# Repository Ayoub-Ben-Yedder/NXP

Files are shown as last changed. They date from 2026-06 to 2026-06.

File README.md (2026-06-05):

# NXP Line Following Robot

An autonomous 2line-following robot built on the Teensy microcontroller with advanced vision-based steering using Pixy2 camera. Designed for precision line tracking with intersection detection and obstacle avoidance.

## Project Overview

This project implements a sophisticated autonomous robot controller that:
- Follows lines detected by Pixy2 camera vision system
- Intelligently handles intersections and corners
- Detects and responds to obstacles using ultrasonic distance sensor
- Recognizes finish line patterns and stops safely
- Applies advanced steering algorithms for smooth, stable tracking

## Hardware Components

### Microcontroller
- **Teensy** (primary controller)

### Sensors
- **Pixy2 Camera** - Line detection and vector tracking
- **HC-SR04 Ultrasonic Sensor** - Distance measurement for obstacle detection
  - TRIG: Pin 14
  - ECHO: Pin 15

### Actuators
- **Servo Motor** - Steering control (Pin 23)
- **DC Motors (x2)** - Left and right propulsion
  - Left Motor: PWM (Pin 8), Direction (Pins 6-7)
  - Right Motor: PWM (Pin 18), Direction (Pins 20-19)

### Additional
- **LED Indicator** - Pin 22
- **Logic Level Converters** - For Pixy2 communication

## Electronics & PCB Design

The electronics are primarily a **Teensy 4.0 shield** custom designed with **KiCAD**. The shield integrates all necessary components (motor drivers, sensor interfaces, power distribution) onto a single PCB that stacks directly onto the Teensy 4.0 microcontroller, providing a clean and compact solution for the robot.

### Schematics
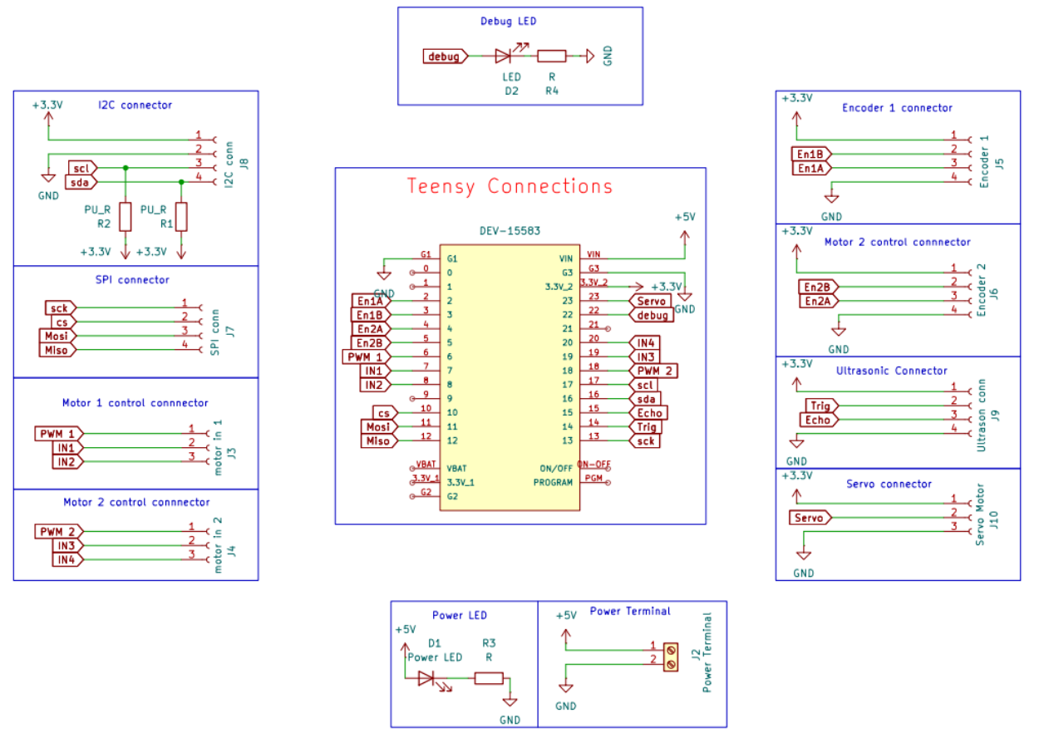
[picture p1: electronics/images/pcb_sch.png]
PCB Schematic


### PCB Layout
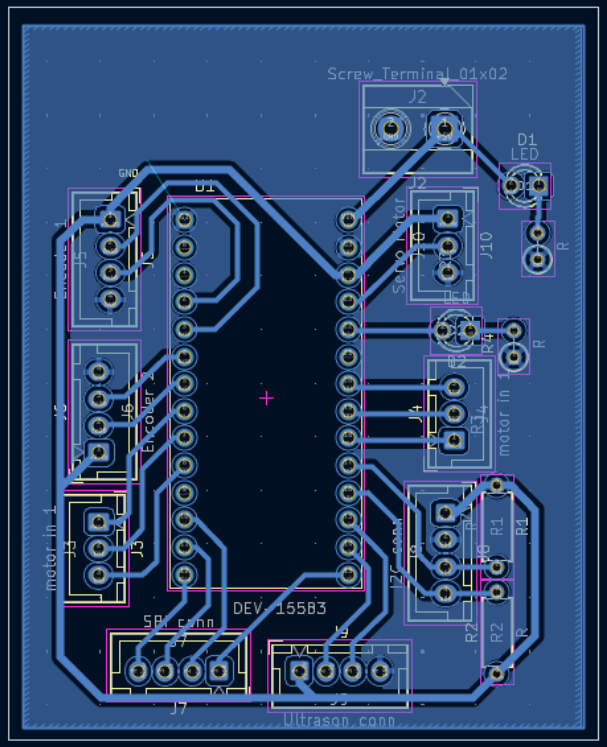
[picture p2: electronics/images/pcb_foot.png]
PCB Footprint


### 3D View
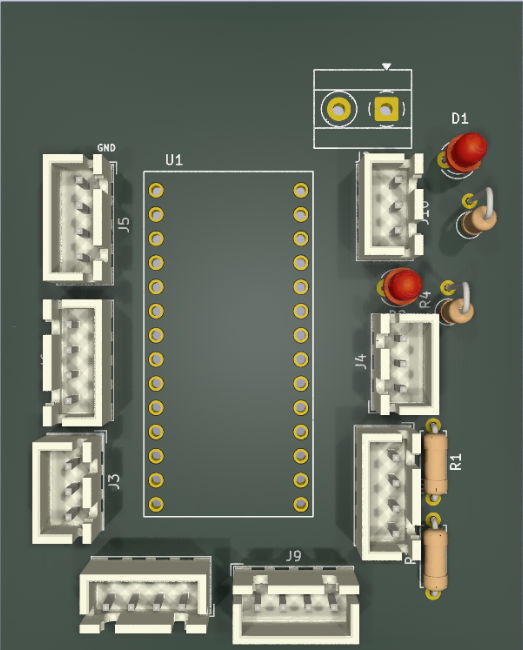
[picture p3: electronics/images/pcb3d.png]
PCB 3D View


All design files are located in the `electronics/` directory.

## Mechanical Design

The mechanical design for this robot was adapted from the [NXP CUP FINALS](https://github.com/aminebensaid66/NXP-CUP-FINALS) repository. This includes the chassis, motor mounts, sensor brackets, and other structural components required for the robot assembly.

## Pin Configuration

```
PWM1 = 8      (Left motor speed)
IN1 = 6       (Left motor direction)
IN2 = 7       (Left motor direction)
PWM2 = 18     (Right motor speed)
IN3 = 20      (Right motor direction)
IN4 = 19      (Right motor direction)

LED = 22
ECHO = 15     (Ultrasonic echo)
TRIG = 14     (Ultrasonic trigger)
SERVO_PIN = 23 (Steering servo)
```

## Key Features

### 1. Advanced Line Following
- Processes up to 20 line vectors from Pixy2 camera
- Weighted steering algorithm that considers vector angles and lengths
- Minimum vector length filtering to ignore noise
- Soft steering limits to prevent oscillation

### 2. Intersection Detection
- Identifies corner types: top-left, top-right, bottom-left, bottom-right
- Analyzes angle between consecutive vectors (target ~90°)
- Applies directional corrections based on intersection position
- More aggressive steering during turns for accuracy

### 3. Steering Control
- **Center Angle:** 135° (neutral position)
- **Steering Range:** 90° (MAX_LEFT) to 180° (MAX_RIGHT)
- **Deadband:** ±15° around forward angle to filter horizontal noise
- **Soft Limiting:** Reduces extreme steering angles to prevent oscillation
- **Center Bias:** Gently pulls steering toward center for stability
- **Delay System:** Smooths steering inputs over 2 cycles

### 4. Obstacle Detection & Avoidance
- Continuously monitors distance via ultrasonic sensor
- Filtered readings (average of 3 samples) for stability
- **Stop Distance:** 15 cm - triggers reverse and stop
- Timeout handling for cases where no object is detected

### 5. Finish Line Recognition
- Detects horizontal line patterns (angle ≤ 15° from horizontal)
- Requires 2+ horizontal vectors within 5 pixels of each other
- Activation delay (10 seconds) to avoid false positives at start
- Triggers acceleration boost and obstacle check

## Build & Upload

This project uses **PlatformIO** for build and upload management.

### Prerequisites
- VSCode with PlatformIO extension
- Arduino IDE libraries (Pixy2, Servo)

### Building
```bash
pio run
```

### Uploading to Device
```bash
pio run --target upload
```

### Monitoring Serial Output
```bash
pio device monitor
```

## Algorithm Flow

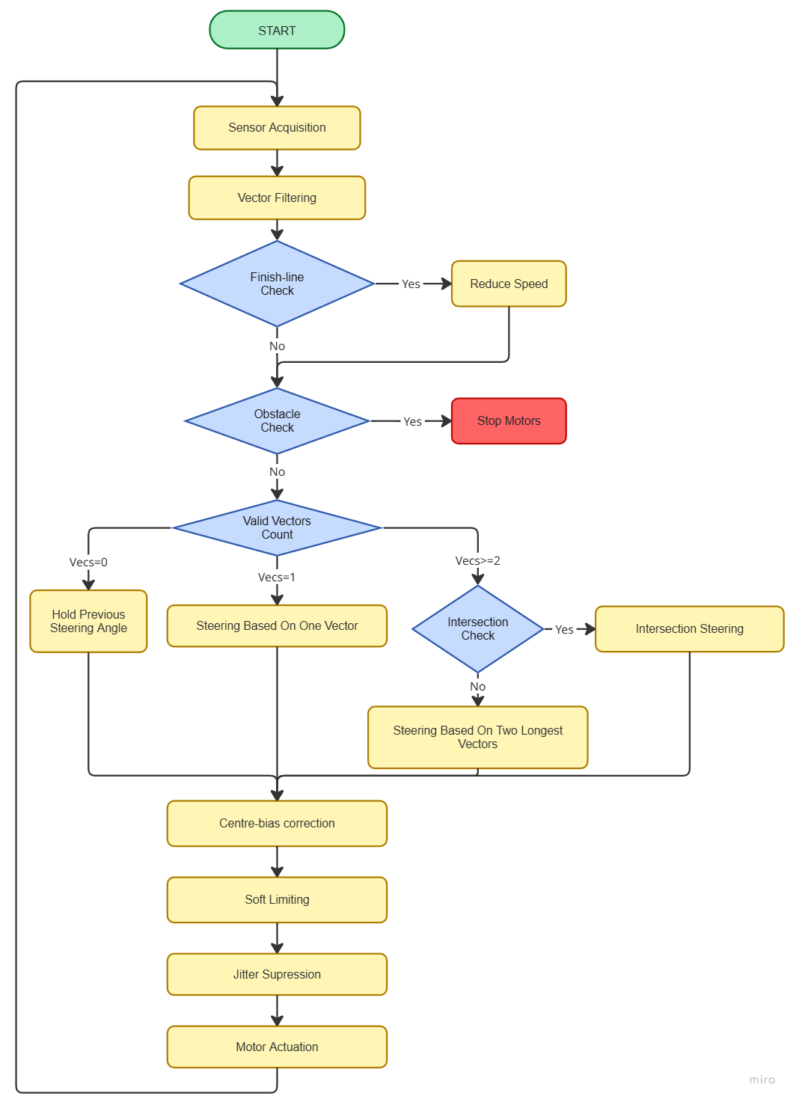
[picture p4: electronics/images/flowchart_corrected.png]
Algorithm Flowchart


1. **Initialization**
   - Configure PWM frequencies (20 kHz)
   - Initialize pins and servo to center
   - Initialize Pixy2 in line-tracking mode
   - Record start time for finish line delay

2. **Main Loop (runNXP)**
   - Read Pixy2 vectors
   - Filter vectors by length, angle, and position
   - Identify horizontal vectors for finish line detection
   - Sort vectors by length (longest first)
   - Compute steering angle based on vector count:
     - **0 vectors:** Maintain last angle
     - **1 vector:** Standard line following
     - **2+ vectors:** Check for intersection; if ~90° angle detected, apply intersection steering
   - Apply steering corrections (center bias, soft limits)
   - Implement steering delay system for smooth transitions
   - Check finish line and obstacle avoidance conditions

3. **Distance Monitoring**
   - Triggered after finish line detection
   - Backs up and stops if obstacle within STOP_DISTANCE

## Constants & Tuning Parameters

```cpp
MAX_VECTORS = 20          // Max vectors to process per frame
MIN_VECTOR_LENGTH = 10    // Minimum pixels for valid vector

CENTRE_ANGLE = 135        // Neutral steering position
MAX_RIGHT = 180           // Maximum right turn
MAX_LEFT = 90             // Maximum left turn

STOP_DISTANCE = 15        // cm - obstacle stop threshold

PIXY_FORWARD_ANGLE = 270  // Expected angle for straight tracking
PIXY_STEER_DEADBAND = 15  // Angle tolerance for horizontal detection
STEERING_DELAY_CYCLES = 2 // Smoothing delay for steering changes
STEERING_QUEUE_THRESHOLD = 2.0   // Threshold to queue steering change
STEERING_CENTER_BIAS = 5.0       // Pull toward center amount
STEERING_SOFT_LIMIT_START = 11   // When to start softening
STEERING_SOFT_LIMIT_FACTOR = 0.5 // Softening strength
CROSS_CORRECTION_ANGLE = 15      // Intersection correction
```

## Performance Notes

- **Steering Response:** Balanced between responsiveness and stability
- **Motor Speed:** Default 150 units for forward motion, 130 for finish line
- **Reverse Speed:** 100 units for obstacle avoidance
- **Frame Rate:** Dependent on Pixy2 refresh rate (typical ~50 FPS)

## Troubleshooting

| Issue | Solution |
|---|---|
| Robot doesn't follow line | Check Pixy2 is in "line" mode; verify camera focus; check lighting |
| Erratic steering | Increase STEERING_DELAY_CYCLES; adjust STEERING_CENTER_BIAS |
| Misses turns | Lower angle threshold in intersection detection; increase CROSS_CORRECTION_ANGLE |
| Oscillates | Enable soft limiting; increase STEERING_SOFT_LIMIT_FACTOR |
| Overshoots finish line | Reduce finish line acceleration value; increase STOP_DISTANCE |

## Project Structure

```
NXP/
├── src/
│   ├── main.cpp          # Main robot controller
│   └── README.md         # This file
├── include/
├── lib/
├── platformio.ini        # Build configuration
└── test/
```

## Future Enhancements

- PID control for smoother steering response
- Dynamic speed adjustment based on turn sharpness
- Gyro integration for improved angle estimation
- Adaptive threshold tuning based on lighting conditions
- Multi-point finish line detection for reliability

---

**Last Updated:** June 2026  
**Board:** Teensy  
**Camera:** Pixy2  
**Competition:** NXP

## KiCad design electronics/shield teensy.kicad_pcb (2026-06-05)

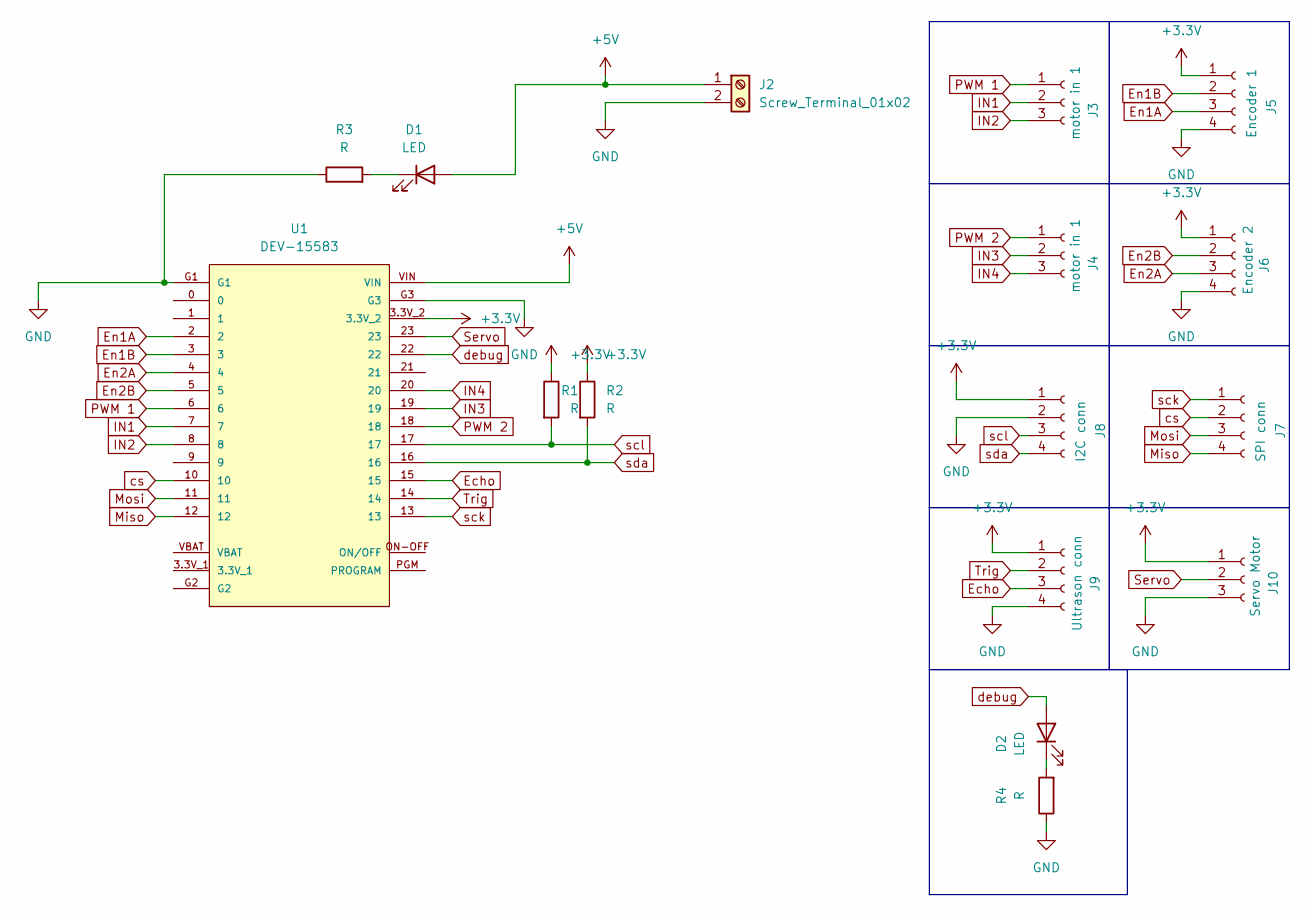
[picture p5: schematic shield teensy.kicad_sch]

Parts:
D1, D2: LED; LED_D3.0mm
J2: Screw_Terminal_01x02; TerminalBlock_MetzConnect_Type055_RT01502HDWU_1x02_P5.00mm_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
J3, J4: motor in 1; JST_XH_B3B-XH-A_1x03_P2.50mm_Vertical
J5: Encoder 1; JST_XH_B4B-XH-A_1x04_P2.50mm_Vertical
J6: Encoder 2; JST_XH_B4B-XH-A_1x04_P2.50mm_Vertical
J7: SPI conn; JST_XH_B4B-XH-A_1x04_P2.50mm_Vertical
J8: I2C conn; JST_XH_B4B-XH-A_1x04_P2.50mm_Vertical
J9: Ultrason conn; JST_XH_B4B-XH-A_1x04_P2.50mm_Vertical
J10: Servo Motor; JST_XH_B3B-XH-A_1x03_P2.50mm_Vertical
R1, R2: R; R_Axial_DIN0207_L6.3mm_D2.5mm_P7.62mm_Horizontal
R3, R4: R; R_Axial_DIN0207_L6.3mm_D2.5mm_P2.54mm_Vertical
U1: DEV-15583; MODULE_DEV-15583

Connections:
+3.3V: J5.1, J6.1, J8.1, J9.1, J10.1, R1.1, R2.1, U1.3.3V_2
+5V: D1.2 (A), J2.1, U1.VIN
Echo: J9.3, U1.15
En1A: J5.3, U1.2
En1B: J5.2, U1.3
En2A: J6.3, U1.4
En2B: J6.2, U1.5
GND: J2.2, J5.4, J6.4, J8.2, J9.4, J10.3, R3.1, R4.1, U1.G1, U1.G3
IN1: J3.2, U1.7
IN2: J3.3, U1.8
IN3: J4.2, U1.19
IN4: J4.3, U1.20
Miso: J7.4, U1.12
Mosi: J7.3, U1.11
unnamed: D1.1 (K), R3.2
unnamed: D2.1 (K), R4.2
PWM 1: J3.1, U1.6
PWM 2: J4.1, U1.18
Servo: J10.2, U1.23
Trig: J9.2, U1.14
cs: J7.2, U1.10
debug: D2.2 (A), U1.22
sck: J7.1, U1.13
scl: J8.3, R1.2, U1.17
sda: J8.4, R2.2, U1.16

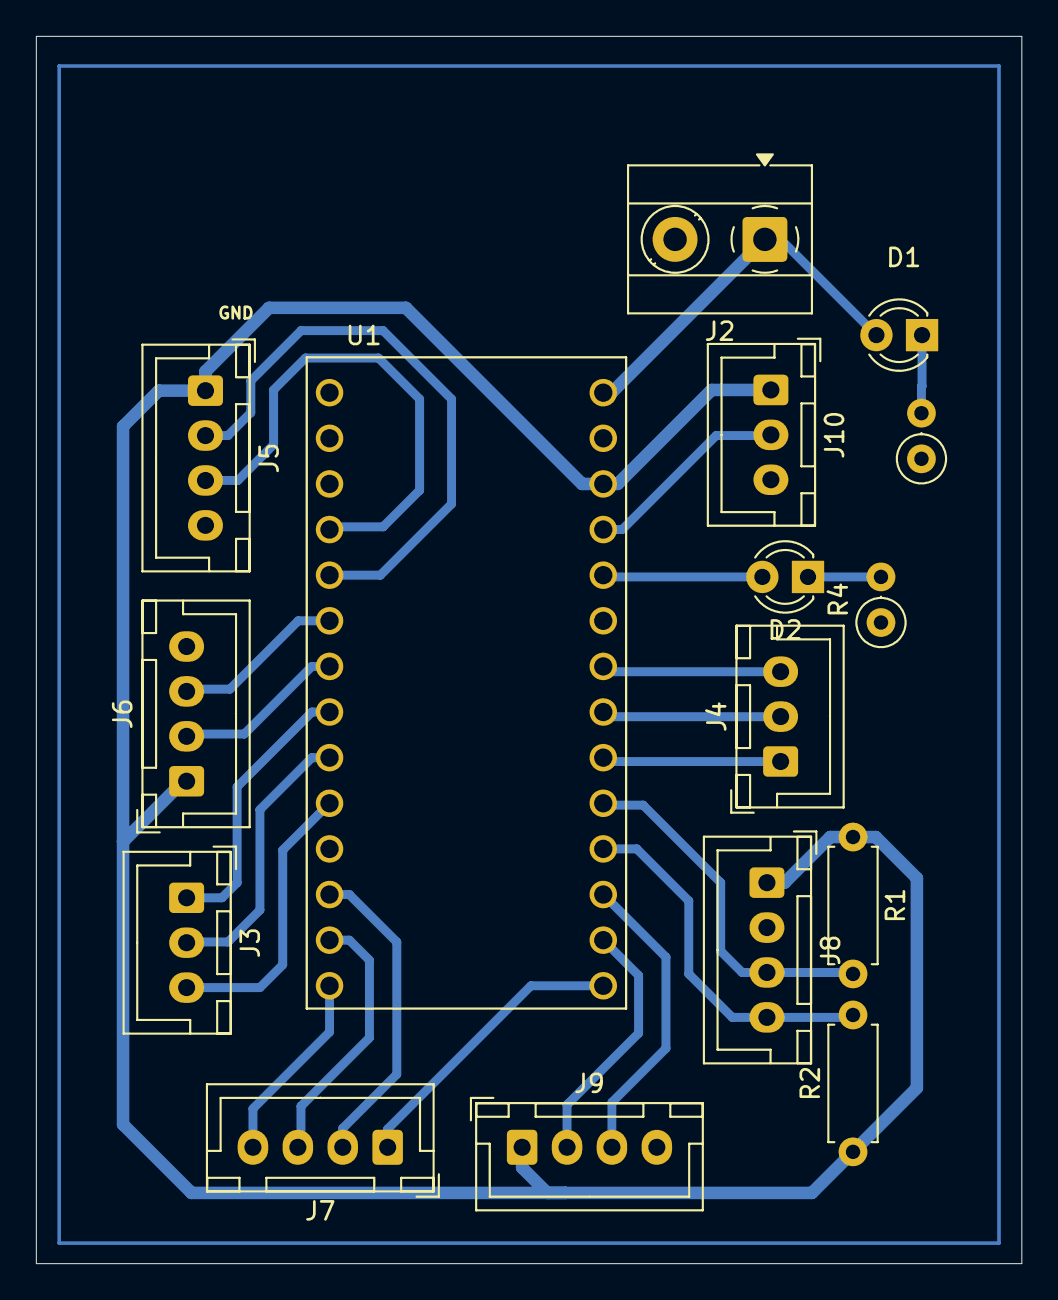
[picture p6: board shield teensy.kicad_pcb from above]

Board: 2 copper layers, 54.9 x 68.3 mm, 16 parts (0 on the bottom side), 25 nets.

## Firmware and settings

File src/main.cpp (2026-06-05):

#include <Arduino.h>
#include <Pixy2.h>
#include <Servo.h>
#include <Wire.h>

// pins definition
#define PWM1 8
#define IN1 6
#define IN2 7
#define PWM2 18
#define IN3 20
#define IN4 19

#define LED 22
#define ECHO 15
#define TRIG 14
#define SERVO_PIN 23

// constants definition

#define MAX_VECTORS 20
#define MIN_VECTOR_LENGTH 10

#define CENTRE_ANGLE 135
#define MAX_RIGHT CENTRE_ANGLE + 45
#define MAX_LEFT CENTRE_ANGLE - 45

#define STOP_DISTANCE 15

#define TOP_LEFT_CORNER 1
#define TOP_RIGHT_CORNER 2
#define BOTTOM_LEFT_CORNER 3
#define BOTTOM_RIGHT_CORNER 4

#define CROSS_CORRECTION_ANGLE 15.0f

constexpr float PIXY_FORWARD_ANGLE = 270.0;
constexpr float PIXY_STEER_DEADBAND = 15.0;
constexpr uint8_t STEERING_DELAY_CYCLES = 2;
constexpr float STEERING_QUEUE_THRESHOLD = 2.0;
constexpr float STEERING_CENTER_BIAS = 5.0;
constexpr float STEERING_SOFT_LIMIT_START = 11.0;
constexpr float STEERING_SOFT_LIMIT_FACTOR = 0.5;

Servo steer_servo;
Pixy2 pixy;
static float lastSteeringAngle = CENTRE_ANGLE;
static float pendingSteeringAngle = CENTRE_ANGLE;
static uint8_t steeringDelayCounter = 0;

bool finishLineDetected = false;

unsigned long startTime;

long readDistance()
{
  digitalWrite(TRIG, LOW);
  delayMicroseconds(2);

  digitalWrite(TRIG, HIGH);
  delayMicroseconds(10);
  digitalWrite(TRIG, LOW);

  long duration = pulseIn(ECHO, HIGH, 5000); // timeout 5ms
  if (duration == 0)
  {
    return 99; // timeout, no object detected
  }
  long distance = duration * 0.034 / 2;       // cm

  return distance;
}

long readDistanceFiltered()
{
  const int numReadings = 3;
  long readings[numReadings];
  long sum = 0;

  for (int i = 0; i < numReadings; i++)
  {
    readings[i] = readDistance();
    sum += readings[i];
    delay(1);
  }

  return sum / numReadings;
}

void initPixy()
{
  pixy.init();
  pixy.changeProg("line");
}

void steer(int angle)
{
  angle = constrain(angle, MAX_LEFT, MAX_RIGHT);
  steer_servo.write(angle);
}

void run(int speedLeft, int speedRight)
{
  speedLeft = constrain(speedLeft, -255, 255);
  speedRight = constrain(speedRight, -255, 255);

  if (speedRight >= 0)
  {
    analogWrite(PWM2, speedRight);
    digitalWrite(IN3, HIGH);
    digitalWrite(IN4, LOW);
  }
  else
  {
    analogWrite(PWM2, -speedRight);
    digitalWrite(IN3, LOW);
    digitalWrite(IN4, HIGH);
  }

  if (speedLeft >= 0)
  {
    analogWrite(PWM1, speedLeft);
    digitalWrite(IN1, LOW);
    digitalWrite(IN2, HIGH);
  }
  else
  {
    analogWrite(PWM1, -speedLeft);
    digitalWrite(IN1, HIGH);
    digitalWrite(IN2, LOW);
  }
}
// compute the angle of a vector in degrees, where 0 is to the right and increases counterclockwise
float computeAngle(const Vector &vec)
{
  float res = atan2(vec.m_y1 - vec.m_y0, vec.m_x1 - vec.m_x0) * 180.0 / PI;
  while (res < 0)
  {
    res += 360;
  }
  while (res >= 360)
  {
    res -= 360;
  }
  return res;
}
// compute the length of a vector
float computeLength(const Vector &vec)
{
  return sqrt(pow(vec.m_x1 - vec.m_x0, 2) + pow(vec.m_y1 - vec.m_y0, 2));
}
// normalize an angle to be within (0, 360)
float normalizeAngle(float angle)
{
  while (angle < 0.0)
  {
    angle += 360.0;
  }
  while (angle >= 360.0)
  {
    angle -= 360.0;
  }
  return angle;
}

bool isHorizontalAngle(float angle)
{
  angle = normalizeAngle(angle);
  return (angle <= PIXY_STEER_DEADBAND || angle >= 360.0 - PIXY_STEER_DEADBAND) || (fabs(angle - 180.0) <= PIXY_STEER_DEADBAND);
}

float mapFloat(float x, float inMin, float inMax, float outMin, float outMax)
{
  return (x - inMin) * (outMax - outMin) / (inMax - inMin) + outMin;
}
// compute the smallest difference between two angles, result is in range (-180, 180)
float angleDelta(float from, float to)
{
  float delta = normalizeAngle(to) - normalizeAngle(from);
  while (delta <= -180.0)
  {
    delta += 360.0;
  }
  while (delta > 180.0)
  {
    delta -= 360.0;
  }
  return delta;
}

float computeSteeringAngle(const Vector *vectors, uint8_t numVectors)
{
  float weightedDelta = 0.0;
  float totalWeight = 0.0;

  for (uint8_t i = 0; i < numVectors; i++)
  {
    float angle = computeAngle(vectors[i]);
    float length = computeLength(vectors[i]);
    float delta = angleDelta(PIXY_FORWARD_ANGLE, angle);

    if (fabs(delta) > 90.0)
    {
      delta = angleDelta(PIXY_FORWARD_ANGLE, normalizeAngle(angle + 180.0));
    }

    float weight = max(length, 1.0f);
    weightedDelta += delta * weight;
    totalWeight += weight;
  }

  float avgDelta = totalWeight > 0.0 ? weightedDelta / totalWeight : 0.0;
  avgDelta = constrain(avgDelta, -45.0, 45.0);
  return mapFloat(avgDelta, -45.0, 45.0, MAX_LEFT, MAX_RIGHT);
}
// bias the steering angle slightly toward the center to help with recovery when we drift to the sides
float biasSteeringTowardCenter(float steeringAngle)
{
  if (steeringAngle > CENTRE_ANGLE)
  {
    return max(CENTRE_ANGLE, steeringAngle - STEERING_CENTER_BIAS);
  }
  if (steeringAngle < CENTRE_ANGLE)
  {
    return min(CENTRE_ANGLE, steeringAngle + STEERING_CENTER_BIAS);
  }
  return steeringAngle;
}
// when the steering angle is beyond a certain threshold from the center, we start to soften it to avoid oversteering and oscillations
float softenExtremeSteering(float steeringAngle)
{
  float delta = steeringAngle - CENTRE_ANGLE;
  float absDelta = fabs(delta);
  if (absDelta <= STEERING_SOFT_LIMIT_START)
  {
    return steeringAngle;
  }

  float sign = delta > 0 ? 1.0f : -1.0f;
  float extra = absDelta - STEERING_SOFT_LIMIT_START;
  float softenedExtra = extra * STEERING_SOFT_LIMIT_FACTOR;
  return CENTRE_ANGLE + sign * (STEERING_SOFT_LIMIT_START + softenedExtra);
}

void sortVectorsByLength(Vector *vectors, uint8_t numVectors)
{
  for (uint8_t i = 0; i < numVectors - 1; i++)
  {
    for (uint8_t j = 0; j < numVectors - i - 1; j++)
    {
      float length1 = computeLength(vectors[j]);
      float length2 = computeLength(vectors[j + 1]);
      if (length1 < length2)
      {
        Vector temp = vectors[j];
        vectors[j] = vectors[j + 1];
        vectors[j + 1] = temp;
      }
    }
  }
}

float applyCorrection(const Vector *vectors, uint8_t numVectors, float targetSteering)
{
 if (numVectors == 1)
  {
    float mainVectorCenterX = (vectors[0].m_x0 + vectors[0].m_x1) / 2.0f; // (x0+x1)/2 mte3 atwel vecteur
    if (fabs(targetSteering - CENTRE_ANGLE) <= 10.0f && mainVectorCenterX >= 20.0f && mainVectorCenterX <= 60.0f)
    {
      float correction = 0.0f;
      if (mainVectorCenterX >= 20.0f && mainVectorCenterX < 40.0f)
      {
        correction = 15.0f; // Small turn to the right
      }
      else if (mainVectorCenterX >= 40.0f && mainVectorCenterX <= 60.0f)
      { 
        correction = -15.0f; // Small turn to the left
      }

      targetSteering = constrain(targetSteering + correction, MAX_LEFT, MAX_RIGHT);
    }
  }
  return targetSteering;
}

float dotProduct(const Vector &v1, const Vector &v2)
{
  return (v1.m_x1 - v1.m_x0) * (v2.m_x1 - v2.m_x0) + (v1.m_y1 - v1.m_y0) * (v2.m_y1 - v2.m_y0);
}

float computeAngleBetweenVectors(const Vector &v1, const Vector &v2)
{
  float mag1 = computeLength(v1);
  float mag2 = computeLength(v2);
  if (mag1 == 0 || mag2 == 0) return 0;
  float dot = dotProduct(v1, v2);
  float cosTheta = dot / (mag1 * mag2);
  cosTheta = constrain(cosTheta, -1.0f, 1.0f);
  return acos(cosTheta) * 180.0 / PI;
}

void stopBox(){
  
  long distance = readDistanceFiltered();
  if(distance < STOP_DISTANCE){
    run(-100,-100);
    delay(200);
    run(0,0);
    while(true);
  }
}
// Identify the type of intersection (corner) formed by two vectors, return 0 if no clear corner is identified, or one of the corner constants if identified
int identifyCase(Vector v1, Vector v2) {
    struct Point { float x, y; };

    Point p1a = {(float)v1.m_x0, (float)v1.m_y0};
    Point p1b = {(float)v1.m_x1, (float)v1.m_y1};
    Point p2a = {(float)v2.m_x0, (float)v2.m_y0};
    Point p2b = {(float)v2.m_x1, (float)v2.m_y1};

    auto distSq = [](Point a, Point b) { 
        return std::pow(a.x - b.x, 2) + std::pow(a.y - b.y, 2); 
    };

    // Find which two ends are the corner
    float d00 = distSq(p1a, p2a);
    float d01 = distSq(p1a, p2b);
    float d10 = distSq(p1b, p2a);
    float d11 = distSq(p1b, p2b);

    Point corner, far1, far2;
    float minDist = std::min({d00, d01, d10, d11});

    if (minDist == d00) { corner = p1a; far1 = p1b; far2 = p2b; }
    else if (minDist == d01) { corner = p1a; far1 = p1b; far2 = p2a; }
    else if (minDist == d10) { corner = p1b; far1 = p1a; far2 = p2b; }
    else { corner = p1b; far1 = p1a; far2 = p2a; }

    // Create vectors pointing AWAY from the corner
    float dir1x = far1.x - corner.x;
    float dir1y = far1.y - corner.y;
    float dir2x = far2.x - corner.x;
    float dir2y = far2.y - corner.y;

    // Normalize them to give them equal weight
    float mag1 = std::sqrt(dir1x*dir1x + dir1y*dir1y);
    float mag2 = std::sqrt(dir2x*dir2x + dir2y*dir2y);
    
    if (mag1 < 0.1f || mag2 < 0.1f) return 0; // Avoid division by zero

    // Resultant vector points into the "open" part of the corner
    float resX = (dir1x / mag1) + (dir2x / mag2);
    float resY = (dir1y / mag1) + (dir2y / mag2);

    
    if (resX < 0 && resY < 0) return TOP_LEFT_CORNER;
    if (resX > 0 && resY < 0) return TOP_RIGHT_CORNER;
    if (resX < 0 && resY > 0) return BOTTOM_LEFT_CORNER;
    if (resX > 0 && resY > 0) return BOTTOM_RIGHT_CORNER;

    return 0;
}
// compute the steering angle when we have an intersection (two vectors with a clear corner), we want to steer more aggressively into the corner to make sure we turn properly, and we also want to apply a correction based on which side of the frame the intersection is on to help with sharper turns
int computeSteeringAngleIntersection(const Vector &v1, const Vector &v2)
{
  float avg_x = (v1.m_x0 + v1.m_x1 + v2.m_x0 + v2.m_x1) / 4.0f;
  float correction_based_on_side = (avg_x < 40.0f) ? CROSS_CORRECTION_ANGLE : ((avg_x > 40.0f) ? - CROSS_CORRECTION_ANGLE : 0.0f); 
  float targetSteering = CENTRE_ANGLE + correction_based_on_side;
  int caseIntersection = identifyCase(v1, v2);
  float caseCorrection = 10.0f;
  if(caseIntersection == TOP_LEFT_CORNER || caseIntersection == BOTTOM_LEFT_CORNER){
    targetSteering += caseCorrection;
  }
  else if(caseIntersection == BOTTOM_RIGHT_CORNER || caseIntersection == TOP_RIGHT_CORNER){
    targetSteering -= caseCorrection;
  }
  return constrain(targetSteering, MAX_LEFT, MAX_RIGHT);
}

void runNXP(){
  Vector vectors[MAX_VECTORS];
  uint8_t numVectors = 0;
  Vector horizontalVectors[MAX_VECTORS];
  uint8_t numHorizontalVectors = 0;
  pixy.line.getAllFeatures();
  for (uint8_t i = 0; i < pixy.line.numVectors; i++)
  {
    float angle = computeAngle(pixy.line.vectors[i]);
    float length = computeLength(pixy.line.vectors[i]);
    int y0 = pixy.line.vectors[i].m_y0;
    int y1 = pixy.line.vectors[i].m_y1;
    float avgY = (y0 + y1) / 2.0f;

    // FINISH LINE DETECTION (need some tuning) First part
    if(isHorizontalAngle(angle) && length < 15.0f){
      horizontalVectors[numHorizontalVectors] = pixy.line.vectors[i];
      numHorizontalVectors++;
    }

    if (numVectors < MAX_VECTORS
        // Ignore vectors that are too short
        && length > MIN_VECTOR_LENGTH
        // Ignore vectors that are too horizontal
        && !isHorizontalAngle(angle)
        // Ignore vectors that are too close to the top or bottom of the frame
        && !((avgY >= 0 && avgY <= 2) || (avgY >= 48 && avgY <= 50)))
    {
      vectors[numVectors] = pixy.line.vectors[i];
      numVectors++;
    }
  }

  // FINISH LINE DETECTION (need some tuning) Second part
  unsigned long elapsedTime = millis() - startTime;
  if(numHorizontalVectors >= 2 && !finishLineDetected && elapsedTime > 10000){
    sortVectorsByLength(horizontalVectors, numHorizontalVectors);
    float avgY_vec1 = (horizontalVectors[0].m_y0 + horizontalVectors[0].m_y1) / 2.0f;
    float avgY_vec2 = (horizontalVectors[1].m_y0 + horizontalVectors[1].m_y1) / 2.0f;
    // if les Y mte3hom ykounou 9ribin mel baadhhom (within 5 pixels), n3etberou finish line detected, w nkamlo douga douga
    if(fabs(avgY_vec1 - avgY_vec2) <= 5.0f){
      finishLineDetected = true;
      run(130,130);
    }
  }

  // Sort vectors by length in descending order
  sortVectorsByLength(vectors, numVectors);

  float targetSteering = lastSteeringAngle;

  if (numVectors == 0)
  {
    targetSteering = lastSteeringAngle;
  }
  else if (numVectors == 1)
  {
    targetSteering = computeSteeringAngle(vectors, numVectors);
  }
  else if (numVectors >= 2)
  {
    // kana fama angle 90 (presque) binet les deux vecteurs, bech nwaslou l goddam (most likely fama intersection)
    float angleBetweenVectors = computeAngleBetweenVectors(vectors[0], vectors[1]);
    if ((abs(angleBetweenVectors) > 70 && abs(angleBetweenVectors) < 110))
    {
      targetSteering = computeSteeringAngleIntersection(vectors[0], vectors[1]);
    }
    // mafamch intersection
    else
    {
      targetSteering = computeSteeringAngle(vectors, numVectors);
    }
  }

  targetSteering = applyCorrection(vectors, numVectors, targetSteering);
  targetSteering = biasSteeringTowardCenter(targetSteering);
  targetSteering = softenExtremeSteering(targetSteering);

  // if the new target steering is significantly different from the last one, queue it
  if (fabs(targetSteering - pendingSteeringAngle) > STEERING_QUEUE_THRESHOLD)
  {
    pendingSteeringAngle = targetSteering;
    steeringDelayCounter = STEERING_DELAY_CYCLES;
  }

  // decrement the delay if we have any
  if (steeringDelayCounter > 0){ steeringDelayCounter--; }

  // if the delay has elapsed and we have a pending steering angle different from the last applied one, apply it
  if (steeringDelayCounter == 0 && pendingSteeringAngle != lastSteeringAngle)
  {
    steer(pendingSteeringAngle);
    lastSteeringAngle = pendingSteeringAngle;
  }

  // Finish line detected, check el box
  if(finishLineDetected){
    stopBox();
  }
}

void setup()
{
  // Set PWM frequency to 20kHz for both channels
  analogWriteResolution(8);
  analogWriteFrequency(PWM1, 20000);
  analogWriteFrequency(PWM2, 20000);
  // Initialize pins
  pinMode(TRIG, OUTPUT);
  pinMode(ECHO, INPUT);
  pinMode(LED, OUTPUT);

  pinMode(PWM1, OUTPUT);
  pinMode(PWM2, OUTPUT);

  pinMode(IN1, OUTPUT);
  pinMode(IN2, OUTPUT);
  pinMode(IN3, OUTPUT);
  pinMode(IN4, OUTPUT);
  // Initialize servo to the center position
  steer_servo.attach(SERVO_PIN);
  steer(CENTRE_ANGLE);

  initPixy();

  digitalWrite(LED, HIGH);

  run(150, 150);
  // Initialize the start time for finish line detection to avoid detecting it too early while we are still at the start
  startTime = millis();
}

void loop()
{
  runNXP();
}
